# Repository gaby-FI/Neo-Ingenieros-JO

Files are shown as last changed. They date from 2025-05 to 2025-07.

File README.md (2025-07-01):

<div align="center">
  
   # Autonomous Robot Project for WRO - Future Engineers Category
  
</div>

## 🤖 About the Competition

The World Robot Olympiad (WRO) is a prestigious international competition that challenges students from around the globe to solve problems through creative, functional, and technically sound robotic solutions. One of its most engaging categories is **Future Engineers**, which focuses on developing advanced technologies to tackle real-world challenges, encouraging innovation, critical thinking, and collaborative work.

This year's challenge in the Future Engineers category is particularly exciting: to design and build an **autonomous vehicle** capable of making intelligent decisions and adapting to a dynamic environment. The challenge offers a unique opportunity for young engineers to explore the fundamentals of modern robotics, including motor control, sensor processing, and autonomous navigation.

---

## 🚗 Project Description

This repository documents the hardware and software architecture developed to build an autonomous vehicle designed to compete in the Future Engineers category of the WRO. The system has been carefully designed to address two specific challenges defined by the competition:

1. **Open Challenge**: The vehicle must complete three laps on a closed track, where inner walls are randomly placed each run. The robot must avoid collisions through accurate obstacle detection.
   
2. **Obstacle Challenge**: Along the route, the robot will encounter colored pillars acting as traffic signals. **Red** pillars indicate the robot should drive on the right, while **green** pillars indicate it should drive on the left. The vehicle must navigate without knocking over these signals, and at the end of the route, it must detect a **parking zone** and autonomously perform parallel parking.

The design integrates multiple technologies: ultrasonic sensors, a gyroscope, a Pixy2 camera, DC motors, and an H-bridge, all controlled by an Arduino Uno microcontroller. The system includes a voltage regulator and capacitors to protect sensitive components and ensure safe, stable operation. This documentation serves as a technical guide for the development process and as a reference for future teams participating in similar robotics challenges

---

## 🎯 Project Objective

The goal of this project is to design, build, and program an autonomous robot using open-source hardware, environmental sensors, and adaptive motion algorithms. The robot dynamically perceives its surroundings and makes decisions based on sensor feedback, enabling efficient navigation and autonomous obstacle avoidance.

**Core development goals:**

- Strengthen real-world engineering skills such as problem-solving and teamwork.
- Apply sensor-based motion control for precise navigation.
- Develop an optimized autonomous driving strategy for robotics challenges.
- Contribute to the open-source robotics community by documenting the solution for future teams.

---

## 🧩 Components Used

| Quantity | Component | Image | Description |
|:---:|:---:|:---:|:---:|
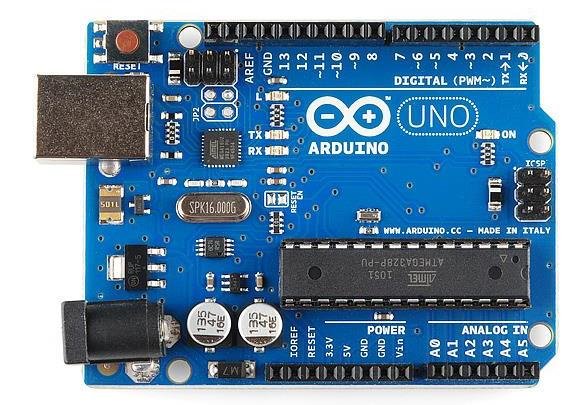
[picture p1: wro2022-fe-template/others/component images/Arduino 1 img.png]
| 1 | Arduino UNO |  | - ATmega328P microcontroller<br>- Operating voltage: 5V<br>- 14 digital pins (6 PWM)<br>- 6 analog inputs<br>- Memory: 32 KB flash, 2 KB SRAM, 1 KB EEPROM<br>- Communication: USB, UART, I2C, SPI<br>- Main system control, sensor reading, PWM signal generation, external communication<br>- Power supply: 7-12V<br>- Easy programming via Arduino IDE |
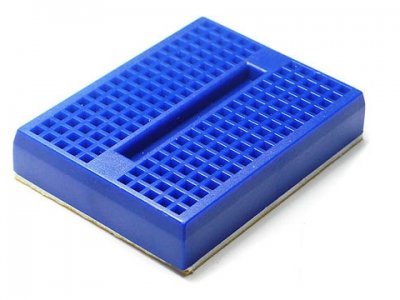
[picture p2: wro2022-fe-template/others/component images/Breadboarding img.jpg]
| 1 | Protoboard |  | - 830 solderless connection points<br>- Enables rapid prototyping<br>- Temporary connections between components<br>- Side rails for power (Vcc and GND)<br>- Compatible with standard cables and pins<br>- Plastic body with internal metal contacts<br>- Ideal for testing circuits without soldering |
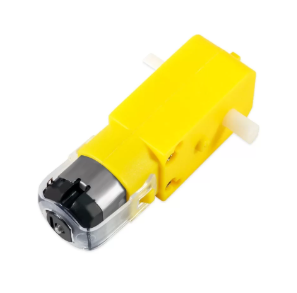
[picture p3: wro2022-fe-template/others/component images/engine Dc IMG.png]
| 2 | DC Engine |  | - Nominal voltage: 6–12V<br>- No-load current: ~300 mA<br>- Brushed DC motor<br>- Provides rotational motion<br>- Controlled via H-bridge for direction and speed<br>- Adequate torque for small vehicles<br>- Compact and lightweight |
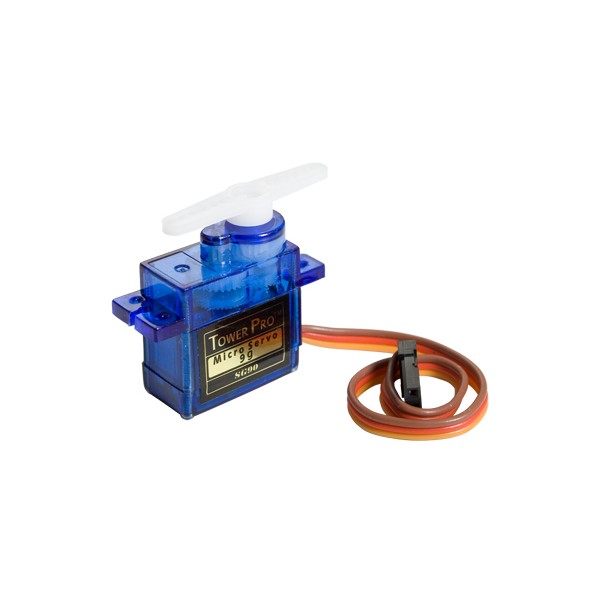
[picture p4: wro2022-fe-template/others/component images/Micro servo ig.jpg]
| 1 | Servo Motor |  | - Operating voltage: 4.8–6V<br>- Max current: ~500 mA<br>- Rotation angle: 0° to 180°<br>- Micro servo with plastic gears<br>- Precise angular position control via PWM<br>- Used for moving sensors or steering<br>- Compact and lightweight |
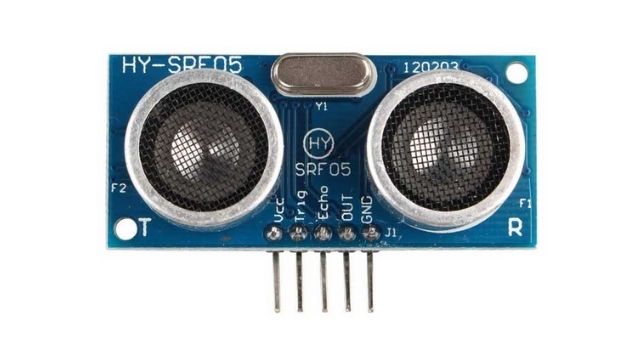
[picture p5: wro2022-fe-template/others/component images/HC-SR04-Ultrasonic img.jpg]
| 2 | Ultrasonic Sensors |  | - Operating voltage: 5V DC<br>- Range: 2 cm to 400 cm<br>- Accuracy: ±3 mm<br>- Ultrasonic frequency: 40 kHz<br>- Pins: Trigger and Echo<br>- Measures distance for obstacle avoidance<br>- Fast response time<br>- Detects objects in a straight line |
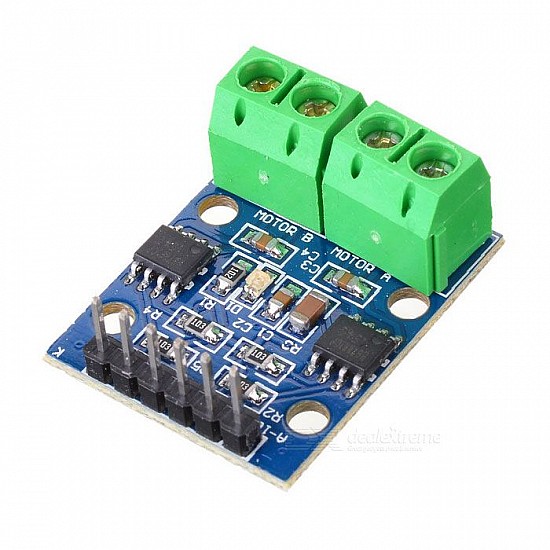
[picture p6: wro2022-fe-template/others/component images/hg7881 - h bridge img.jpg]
| 1 | HG7881 H-Bridge |  | - Operating voltage: 2.5–12V<br>- Max current: 800 mA per channel<br>- Dual channel motor driver<br>- Controls motor direction and speed via PWM<br>- Includes internal protection diodes<br>- Compact and efficient for small projects |
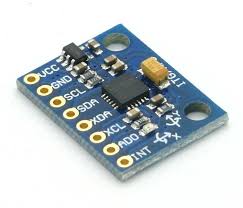
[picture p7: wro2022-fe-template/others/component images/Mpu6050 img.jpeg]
| 1 | MPU-6050 Gyroscope |  | - Power supply: 3.3V–5V<br>- 3-axis gyroscope and 3-axis accelerometer<br>- I2C communication<br>- High precision for orientation and balance<br>- Used for stabilization and motion tracking<br>- Low power consumption |
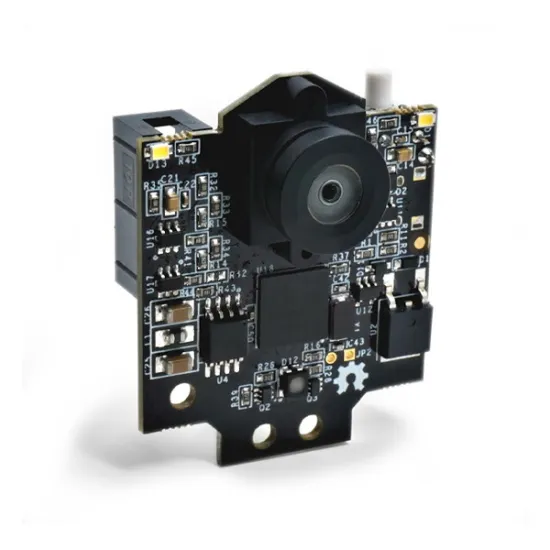
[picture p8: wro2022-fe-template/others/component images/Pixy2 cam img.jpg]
| 1 | Pixy2 Camera |  | - Operating voltage: 5–10V DC<br>- Communication: SPI, UART, I2C<br>- Smart sensor for object detection and tracking by color<br>- Internal image processing<br>- Sends processed data for decision making<br>- Used for advanced navigation and tracking |
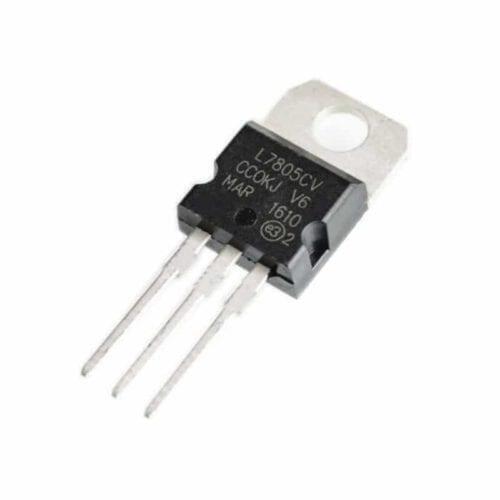
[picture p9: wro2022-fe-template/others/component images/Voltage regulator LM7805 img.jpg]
| 1 | Voltage Regulator |  | - Input voltage: 7–12V DC<br>- Fixed output: 5V DC<br>- Max current: typically 1A<br>- Provides stable and filtered voltage<br>- Overvoltage and thermal protection<br>- Protects sensitive components |
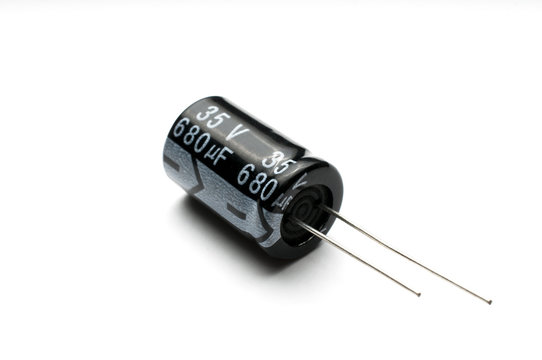
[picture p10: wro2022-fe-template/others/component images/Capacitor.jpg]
| 3 | Capacitors |  | - Electrolytic polarized capacitors (100μF, 10μF)<br>- Filters electrical noise and voltage spikes<br>- Stabilizes power supply<br>- Temporary charge storage<br>- Placed near regulators and modules<br>- Improves system stability and performance |

---

## 🔄 Relationship Between Electromechanical Components

- 🧠 The **Arduino UNO** acts as the brain of the vehicle, receiving data from sensors and sending control signals to actuators to coordinate movement.

- 📏 The **ultrasonic sensors** send distance information to the Arduino about side obstacles, allowing adjustment of direction and speed to avoid collisions.

- 🌀 The **MPU-6050 gyroscope** provides orientation and angular velocity data to the Arduino, which uses it to stabilize and correct the vehicle’s trajectory.

- 🎥 The **Pixy2 camera** complements the system’s vision by detecting objects and helping the Arduino follow routes or identify specific targets.

- ⚙️ The **HG7881 H-Bridge** receives commands from the Arduino to control the direction and speed of the **DC motors**, enabling forward, backward, and turning movements.

- 🔩 The **DC motors** execute the commands received from the HG7881, converting electrical energy into physical movement to drive the vehicle.

- 🔌 The **voltage regulator** supplies stable and safe voltage to the Arduino, sensors, servo, and HG7881 controller, protecting the electronic components.

- ↪️ The **servo motor** adjusts steering or sensor orientation based on control signals from the Arduino, improving maneuverability and environmental scanning.

- 🔋 The **capacitors** filter electrical noise and stabilize voltage, ensuring sensors, Arduino, and HG7881 operate without interference.

- 🧩 The **protoboard** facilitates physical connections and distribution of power and signals among all components, allowing organized and flexible assembly without soldering.

Each component depends on the information or energy it receives and transmits to others, creating a coordinated system where sensors detect the environment, the Arduino processes information, and actuators like motors and servos execute the necessary actions for the vehicle’s proper operation.

---
## 🚗 Strategy and Code Deployment for Autonomous Vehicle Project

The designed strategy combines mechanical, electronic, and perception components to simulate an intelligent vehicle that autonomously navigates a route under conditions similar to a controlled urban environment. The key elements to meet the challenges are:

- ⚙️ **Motorization and Steering:**  
  An electric motor drives the rear wheels of the vehicle, while a servo motor on the front axle allows left and right steering maneuvers, imitating a real car's steering system.

- 🎥 **Vision and Perception:**  
  A front-mounted camera enables detection of obstacle distances and traffic light colors (red or green), a critical decision factor to deviate either right or left. This visual component acts as the main perception system for the frontal environment.

- 📡 **Side Sensors:**  
  Two ultrasonic sensors located on the vehicle's sides measure the distance to obstacles on each side. Based on this data, the system determines the safest side to turn when detecting an obstruction or needing to take a curve.

- 🧭 **Orientation System:**  
  A gyroscope allows the vehicle to recognize its spatial orientation, record the initial position, and ensure that at the end of the route it parks parallel at the same starting position. This component is essential to meet the precise navigation requirements of the competition.

---
## 🧠 General Code Structure

This project is divided into functional modules that manage the behavior of an autonomous robot. Below is an overview of the main components of the code:

### 1. 📚 Library Imports
Essential libraries are included to:
- Control the **servo motor**.
- Enable **I2C communication**.
- Interface with the **MPU6050 gyroscope sensor**.

These libraries simplify hardware interaction and keep the code modular.

### 2. 🧩 Pin and Object Definitions
Microcontroller pins are assigned to the motors, ultrasonic sensors, and servo. Objects are also created for the servo and gyroscope to manage their operation.

### 3. ⚙️ Variables and Constants
Constants define decision thresholds (e.g., safe distances to avoid obstacles), and global variables are used to store values like rotation and timing.

### 4. 🔧 Initial Setup
In the `setup()` function:
- Pins are configured.
- I2C communication is initialized.
- The MPU6050 sensor is initialized and tested.
- The servo motor is attached.

The serial monitor confirms whether sensors are functioning correctly.

### 5. 📏 Ultrasonic Sensor Readings
Functions are included to measure distance using ultrasonic sensors on the left and right. This helps the robot detect obstacles and make directional decisions accordingly.

### 6. 🚗 Movement Functions
Basic movement functions are defined:
- **Move forward**
- **Move backward**
- **Stop**

These directly control the motor pins and determine the robot's mobility.

### 7. 🔁 Main Loop (`loop`)
The core of the program:
- Gyroscope data is captured.
- Rotational velocities are integrated to calculate orientation angles.
- Data is printed to the serial monitor for debugging or tuning.

There is also commented-out logic that could enable obstacle-avoidance behavior using the ultrasonic sensors.This modular structure makes it easy to scale the system, such as adding more sensors, a camera, or other peripherals without overcomplicating the main codebase.

---

## 💻 Code Compilation and Upload Process

### ⚙️ Development Environment Installation

To work on this project, you need the appropriate environment. It is recommended to use the Arduino IDE, preferably version 1.8.19 or higher, to ensure compatibility with all the libraries used and to avoid compilation errors.

**📚 Required Libraries:**

- `Servo.h`: Enables control of servo motors.  
- `Pixy2.h`: Provides functions necessary to communicate with the Pixy2 vision sensor.

These libraries can be easily installed from the Arduino IDE Library Manager or manually downloaded from their respective repositories.

### 🗂 Project Structure

The source code must be organized properly to ensure correct functionality. All `.ino` files should be located within the same folder, which must be named exactly as the main file (usually `main.ino`). This structure is required by the Arduino IDE to properly compile the different modules of the project.

### ⚙️ Compilation Process

Before compiling the code, configure the environment as follows:

1. Go to **Tools > Board**, and select the appropriate board model — in this case, **Arduino UNO**.  
2. In the same menu, select the COM port to which your device is connected.  
3. Once configured, click the **Verify** button (✔️) to compile the code. This action translates the source code to machine language and detects syntax errors or library issues.

### 🚀 Uploading the Program

Once the code is compiled:

1. Connect the Arduino UNO board to your computer via USB cable.  
2. Press the **Upload** button (➡️) in the IDE to load the program into the microcontroller’s memory.  
3. After upload completes, you can monitor the system behavior using the **Serial Monitor** accessible from **Tools > Serial Monitor**, which is especially useful for debugging and data flow verification

---

## 👥 Authors

This project was developed by the **Neo Engineers** team for the **WRO 2025** competition.  
Participants:  
- Nelson Figueroa  
- Gabriela Cisnero  
- Jesus Alfonzo

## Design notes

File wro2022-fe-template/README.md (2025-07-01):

Engineering materials
====

This repository contains engineering materials of a self-driven vehicle's model participating in the WRO Future Engineers competition in the season 2022.

## Content

* `t-photos` contains 2 photos of the team (an official one and one funny photo with all team members)
* `v-photos` contains 6 photos of the vehicle (from every side, from top and bottom)
* `video` contains the video.md file with the link to a video where driving demonstration exists
* `schemes` contains one or several schematic diagrams in form of JPEG, PNG or PDF of the electromechanical components illustrating all the elements (electronic components and motors) used in the vehicle and how they connect to each other.
* `src` contains code of control software for all components which were programmed to participate in the competition
* `models` is for the files for models used by 3D printers, laser cutting machines and CNC machines to produce the vehicle elements. If there is nothing to add to this location, the directory can be removed.
* `other` is for other files which can be used to understand how to prepare the vehicle for the competition. It may include documentation how to connect to a SBC/SBM and upload files there, datasets, hardware specifications, communication protocols descriptions etc. If there is nothing to add to this location, the directory can be removed.

---

<div align="center">
  
   # Autonomous Robot Project for WRO - Future Engineers Category
  
</div>

## 🤖 About the Competition

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

---

## 🚗 Project Description

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

---

## 🎯 Project Objective

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

**Core development goals:**

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

---

## 🧩 Components Used

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

---

## 🔄 Relationship Between Electromechanical Components

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

- 🔋 The **capacitors** filter electrical noise and stabilize voltage, ensuring sensors, Arduino, and HG7881 operate without interference.

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

---
## 🚗 Strategy and Code Deployment for Autonomous Vehicle Project

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

---
## 🧠 General Code Structure

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

These libraries simplify hardware interaction and keep the code modular.

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

The serial monitor confirms whether sensors are functioning correctly.

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

### 6. 🚗 Movement Functions
Basic movement functions are defined:
- **Move forward**
- **Move backward**
- **Stop**

These directly control the motor pins and determine the robot's mobility.

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

---

## 💻 Code Compilation and Upload Process

### ⚙️ Development Environment Installation

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

**📚 Required Libraries:**

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

### 🗂 Project Structure

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

### ⚙️ Compilation Process

Before compiling the code, configure the environment as follows:

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

### 🚀 Uploading the Program

Once the code is compiled:

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

---

## 👥 Authors

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

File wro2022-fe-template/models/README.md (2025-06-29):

Models irectory
===

This directory is for the files for **models used by 3D printers, laser cutting machines, and CNC machines** to produce the vehicle elements.

It includes all the digital design files required to fabricate structural and mechanical parts of the vehicle, such as:

- Chassis components
- Sensor or camera mounts
- Motor brackets
- Enclosures or protective covers

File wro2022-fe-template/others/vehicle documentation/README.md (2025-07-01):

<div align="center">
  
# Vehicle Documentation

### Development and construction of an autonomous vehicle for the World Robot Olympiad (WRO)
---
</div>

This document provides a detailed description of the development, construction, and validation of an autonomous vehicle designed to compete in the World Robot Olympiad (WRO). The main technical objective was to enable the robot to complete three laps on a closed circuit, accurately avoiding walls and intermediate obstacles.

Throughout the process, challenges were addressed in three key areas: mechanics, electronics, and intelligent control. Through multiple technical iterations, both the physical design and navigation algorithm were optimized, resulting in a robust, reliable system capable of meeting the competition's demanding requirements

---

## ✏️ Phase 1 – Concept Design and LEGO-Based Prototype

The initial phase focused on designing the robot based on dimensional sketches and functional concepts to ensure maneuverability and performance.

### 🧱 Physical Build

- A preliminary chassis was constructed using **LEGO pieces**, which allowed quick prototyping and a clear visual of the intended structure.
- Special attention was given to selecting **agile wheels**, aiming for smooth mobility and accurate turns.

### 🔌 Initial Electronics Setup

- **Microcontroller:** Arduino UNO
- **Ultrasonic Sensors (2x):** Used for obstacle detection in front and side directions  
- **Rear-Wheel Movement:** Driven by a DC motor  
- **Motor Controller:** L298N H-Bridge  
- **Power Supply:** Elegoo battery  
- **Arduino Adapter Board:** Used to simplify wiring and component connections  

This stage provided the robot with basic movement capabilities and established a foundation for future integration.

---

## ⚙️ Phase 2 – Sensor Integration and Functional Expansion

Once the robot could move independently, additional components were added to meet competition demands and allow environmental interaction.

### 🔍 Installed Modules

- **Pixy2 Camera:** Enabled object or color tracking through visual input  
- **Servo Motor:** Allowed the robot to control the steering angle and change direction autonomously  

These upgrades allowed the robot to interpret its surroundings and make decisions based on sensor input, increasing its level of autonomy.

<div align="center">
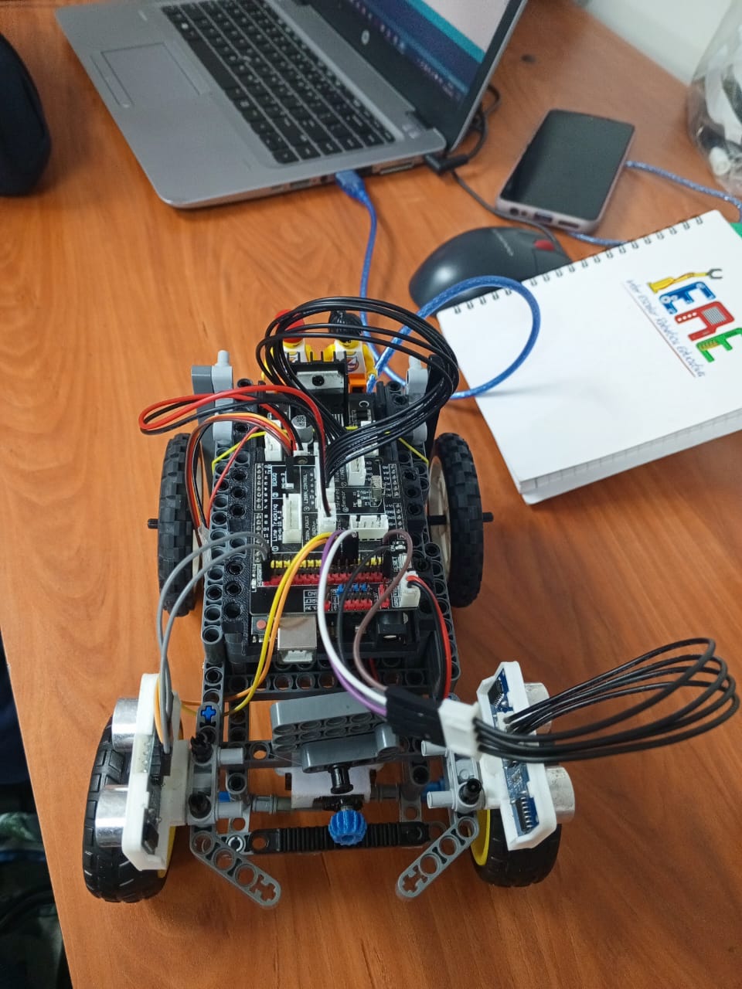
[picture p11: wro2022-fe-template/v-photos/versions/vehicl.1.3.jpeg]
  
  
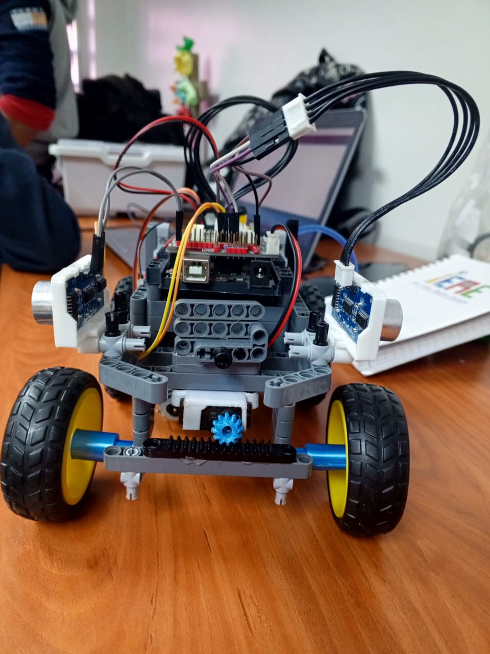
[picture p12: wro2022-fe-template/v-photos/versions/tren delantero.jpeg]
  

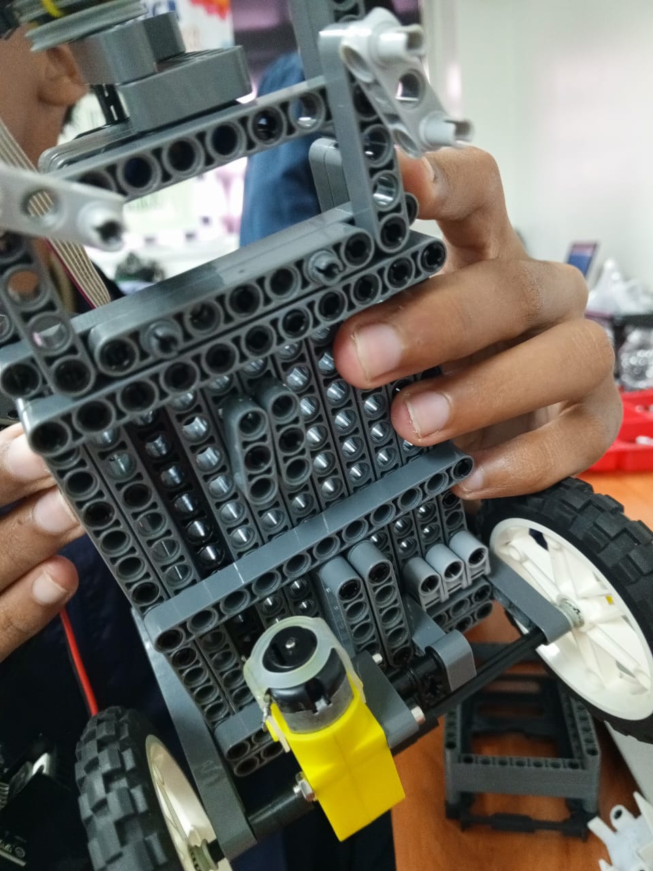
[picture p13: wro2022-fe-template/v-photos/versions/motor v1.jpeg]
  
</div>

---

## 🛠️ Phase 3 – Hardware Reinforcement and Electrical Optimization

After testing, several issues were identified with the robot's structure and electrical system, leading to necessary improvements.

### 🧩 Mechanical Adjustments

- The **rear wheel system** built with LEGO was unstable. It was replaced with a **3D-printed gear mechanism**, enabling better torque transfer, improved rotation smoothness, and higher vehicle speed.

### ⚡ Power and Control Upgrades

- The **Elegoo battery** was replaced by **three 3.5V batteries connected in series**, offering increased voltage and more consistent power output.
- The **L298N motor driver** was swapped for an **HG7881 driver**, which consumed less voltage and required fewer GPIO pins on the microcontroller.

These changes greatly enhanced the robot’s mechanical stability, energy efficiency, and response time.

---

## 🚀 Phase 4 – Final Additions and Advanced Control

In the final development phase, the robot was equipped with advanced modules to increase precision and control capabilities.

### 🧠 New Features

- **Gyroscope:** Used to store the robot’s initial coordinates and return to the original position (self-parking logic)
- **Power Button:** Manually activates battery flow to the circuit
- **Breadboard:** Used to expand ground and voltage lines, improving wiring organization
- **Upgraded Front Steering:** Implemented using **3D-printed components**, increasing directional control and structural strength

<div align="center">
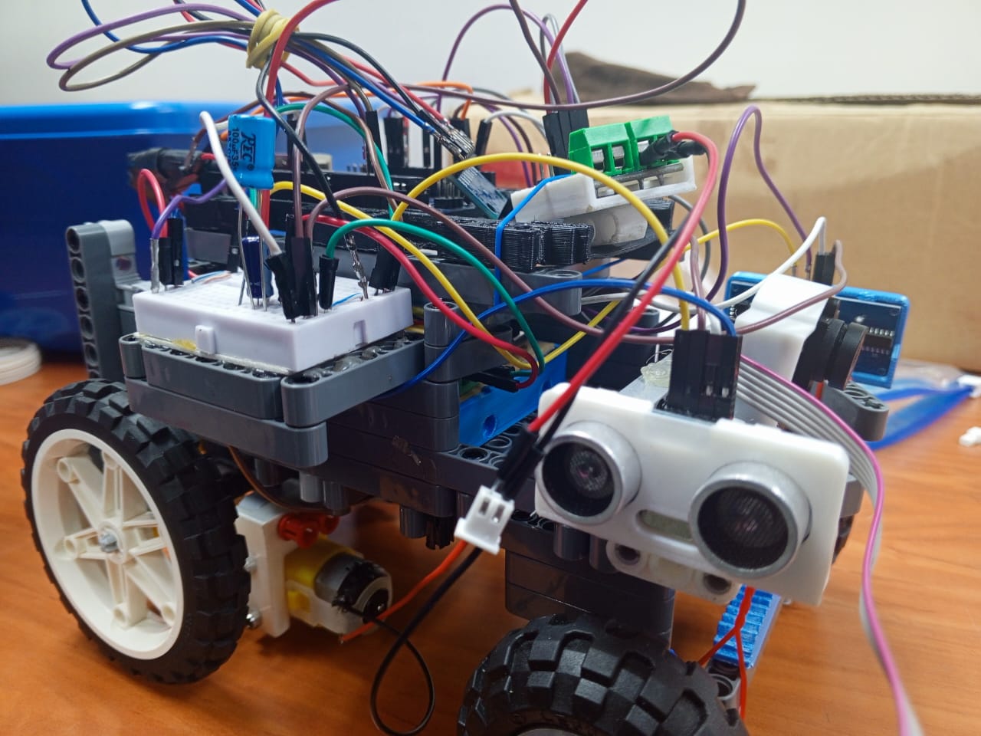
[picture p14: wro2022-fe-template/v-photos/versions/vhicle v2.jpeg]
  
  
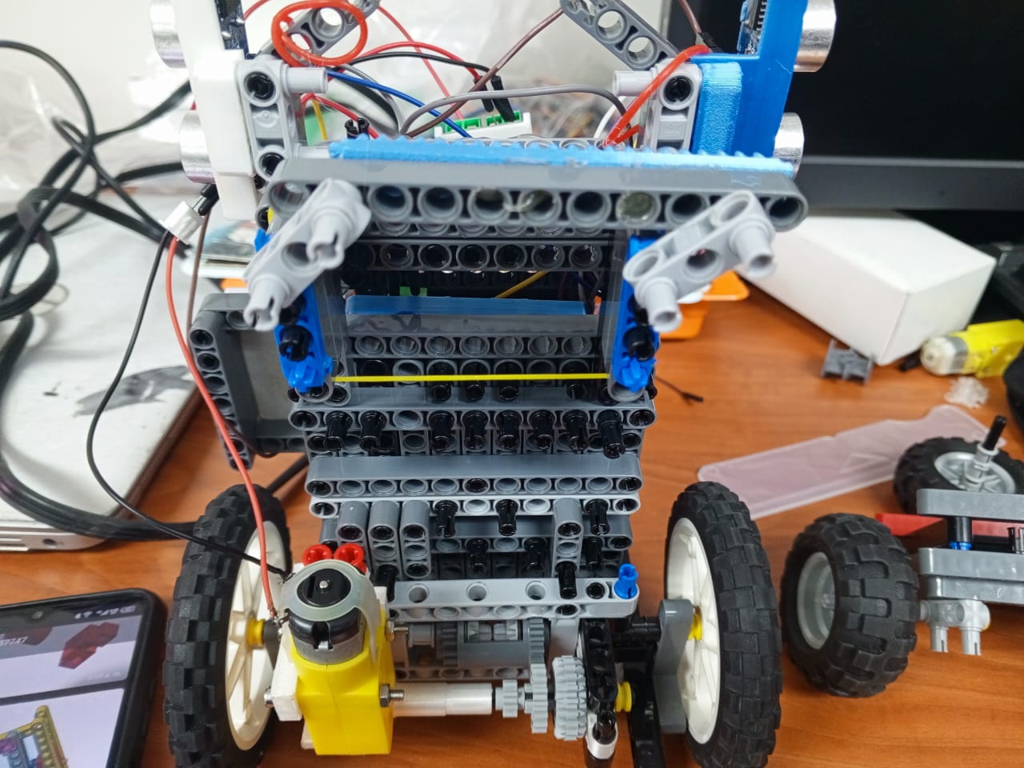
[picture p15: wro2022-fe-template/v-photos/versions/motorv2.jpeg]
  

</div>

## 🧠 Conclusion

The robot's development followed a structured, iterative approach. From simple sketches and LEGO prototyping to advanced sensor integration and 3D-printed enhancements, the vehicle evolved into a robust, efficient, and autonomous machine ready for competition. The final design prioritizes stability, power efficiency, and intelligent navigation.

---

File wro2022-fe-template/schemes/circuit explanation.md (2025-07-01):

# 🤖 Circuit Diagram - WRO Future Engineers

This repository contains the wiring diagram for the electromechanical system of the autonomous vehicle developed for the **WRO Future Engineers 2022** project. The system integrates motors, sensors, controllers, and a regulated power supply to allow coordinated and safe operation of the vehicle.

## 🧩 Components Used

| Quantity | Component | Image | Description |
|:---:|:---:|:---:|:---:|
| 1 | Arduino UNO |  | Main microcontroller board used to control all components. |
| 1 | Protoboard |  | Solderless board used for building and testing electronic circuits. |
| 1 | DC engine |  | Motors used for the vehicle’s locomotion. |
| 1 | Servo Motor |  | Controls the steering or sensor orientation. |
| 2 | Ultrasonic Sensors |  | Distance measurement (Left and Right side). |
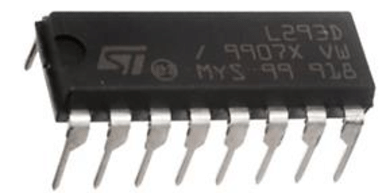
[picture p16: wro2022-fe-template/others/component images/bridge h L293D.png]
| 1 | L293D H bridge |  | Motor driver that allows control of direction and speed for two DC motors.(Used only in the diagram; the actual vehicle circuit uses an HG7881 instead.) |
| 1 | MPU-6050 Gyroscope |  | Detects angular motion and helps with orientation. |
| 1 | Pixy2 Camera |  | Visual object detection system. |
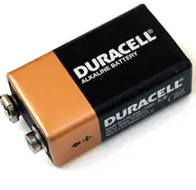
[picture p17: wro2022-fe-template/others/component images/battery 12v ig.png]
| 1 | 12V Battery |  | 12V power source for motors and logic components. (In the actual circuit, three 3.5V batteries connected in series using a battery holder are used instead). |
| 1 | Voltage Regulator |  | Steps down 12V to 5V to protect components from overvoltage. |
| 2 | Condenser |  | Filters electrical interference and stabilizes voltage in the circuit. |

## 📷 Circuit Diagram

> Full connection diagram (created in Tinkercad)

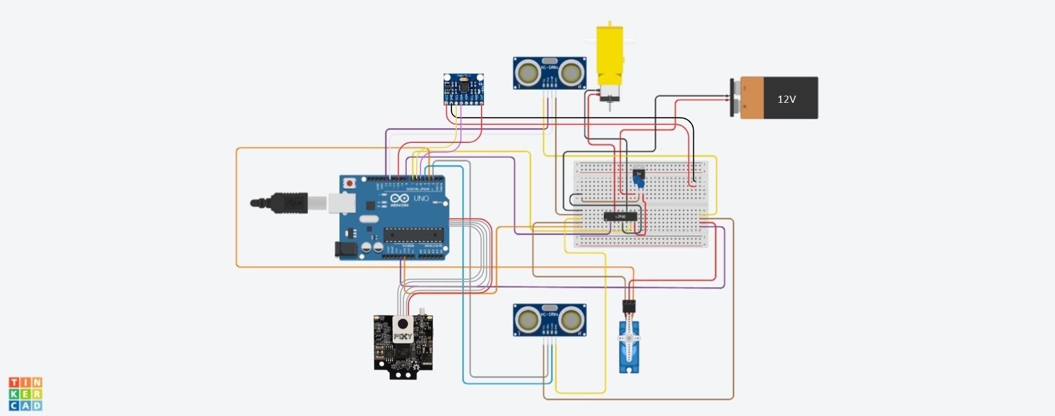
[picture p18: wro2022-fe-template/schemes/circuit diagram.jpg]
Circuit diagram


## 🔌 Wiring Explanation

### 🔊 Ultrasonic Sensors

**Left sensor:**
- Trigger (purple) → Pin 13  
- Echo (white) → Pin 12  
- VCC (yellow) → Breadboard power rail  
- GND (brown) → Breadboard ground rail  

**Right sensor:**
- Trigger (gray) → Pin 2  
- Echo (blue) → Pin 4  
- VCC → Breadboard power rail  
- GND → Breadboard ground rail  

### ⚙️ DC Motors and H-Bridge (L298N)

- Motors connected to channel A of the H-Bridge (purple and gray wires)  
- IN1 → Pin 8  
- IN2 → Pin 7  
- H-Bridge GND → Breadboard ground  
- H-Bridge VCC → Output from voltage regulator  

### 🌀 Gyroscope MPU-6050

- VCC (red) → Breadboard power rail  
- GND (black) → Breadboard ground rail  
- SDA (purple) → Pin A4  
- SCL (gold) → Pin A5  
- INT (thin red) → Pin 11  

### 🔁 Servo Motor

- Signal (orange) → Pin 3  
- VCC (red) → Power rail  
- GND (brown) → Ground rail  

### 📷 Pixy2 Camera

- Connected to Arduino via dedicated interface cable (UART or SPI).

### 🔋 Voltage Regulator Circuit

- **12V Battery:**
  - Positive → Right leg of the regulator (input)  
  - Negative → Shared ground  
- **Regulator:**
  - Left leg → 5V output (goes to H-Bridge and breadboard)  
  - Middle leg → GND (connected to ground rail)  
- **Capacitors:**
  - One large capacitor between output and GND  
  - One smaller capacitor between input and GND  

> This setup reduces the 12V from the battery to 5V to avoid overloading the H-Bridge and ensures safe current regulation to protect the motors and board.

## ⚠️ Recommendations

- Make sure all grounds (GND) are unified to avoid floating references.  
- Motors are powered directly from the H-Bridge and battery.  
- The voltage regulator prevents current spikes that could damage components and guarantees stable 5V output for the electronics.

## ✅ Justification of Component Selection
### 🧠 **Arduino UNO**  
Chosen as the main microcontroller for its ease of programming, multiple I/O ports, and compatibility with various modules. It handled all sensor inputs, motor control, and decision-making processes efficiently during the development and testing stages.

### ⚙️ **DC Motor**  
Used for the main propulsion system of the vehicle. These motors convert electrical energy into mechanical movement, enabling the robot to navigate the track reliably with sufficient torque and speed.

### 🔌 **Breadboard**  
Used to simplify prototyping without soldering. It allowed rapid assembly and reconfiguration of the circuit, especially for distributing power and connecting sensors during testing and debugging phases.

### 📏 **HC-SR04 Ultrasonic Sensor**  
Implemented for obstacle detection and distance measurement. Mounted on the sides, these sensors allowed the vehicle to maintain a safe distance from walls and objects, supporting lateral alignment and collision avoidance.

### 🌀 **MPU-6050**  
Provided orientation and motion data through its built-in accelerometer and gyroscope. This information was used to stabilize the vehicle and assist in trajectory adjustments during operation.

### ↪️ **Micro Servo Motor (SG90)**  
Controlled the front steering mechanism of the vehicle. Based on inputs from the ultrasonic sensors and vision system, the servo motor dynamically adjusted the wheel direction to avoid obstacles and follow the correct path.

### 🎥 **Pixy2 Cam**  
Served as the visual processing unit for the vehicle. It enabled real-time object detection and line tracking, allowing the robot to follow a predefined path or identify specific targets during competition scenarios.

### 🔋 **Capacitors**  
Added to the circuit to filter out electrical noise and stabilize voltage across sensitive components. This ensured smoother operation, especially under varying motor loads.

### 🔋 **12V Battery**  
Served as the primary power source for motors and control modules. While a 12V battery is shown in the diagram for simplicity, the actual vehicle used three 3.7V batteries connected in series via a battery holder (totaling ~11.1V), which met all power requirements effectively.

### ⚡ **Voltage Regulators**  
Used to supply consistent 5V output to logic-level components from a higher voltage input. This protected the microcontroller and sensors from voltage spikes or drops.

### 🔀 **HG7881 H-Bridge Motor Driver** *(used in the final vehicle)*  
Enabled bidirectional control of DC motors with PWM support. Its compact design and efficient performance made it ideal for integrating into the mobile platform, controlling both speed and direction.

### 🔄 **L293D H-Bridge** *(used only in the diagram)*  
Included in the schematic as a visual placeholder. It supports bidirectional control of two DC motors and represents the logic of the system. *(In the physical vehicle, the HG7881 was used instead.)*

### 🔋 **Batería de 12V**  
Utilizada como fuente principal de energía para los motores y módulos de control. Aunque en el diseño final se utilizaron tres baterías de 3.7V conectadas en serie mediante un portapilas (equivalente a ~11.1V), la batería de 12V fue representada en el esquema por simplicidad y disponibilidad. Ambas opciones cumplen con los requerimientos de potencia del sistema.

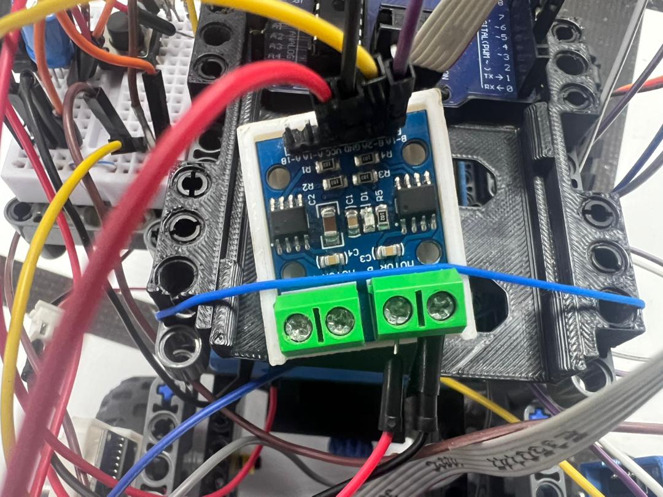
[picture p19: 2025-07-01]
wro2022-fe-template/v-photos/vehicle/puente h.jpeg

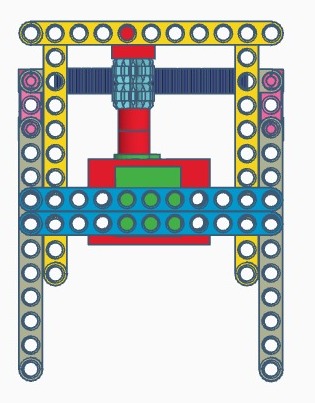
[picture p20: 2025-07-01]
wro2022-fe-template/models/front mechanism/part1.1.jpeg

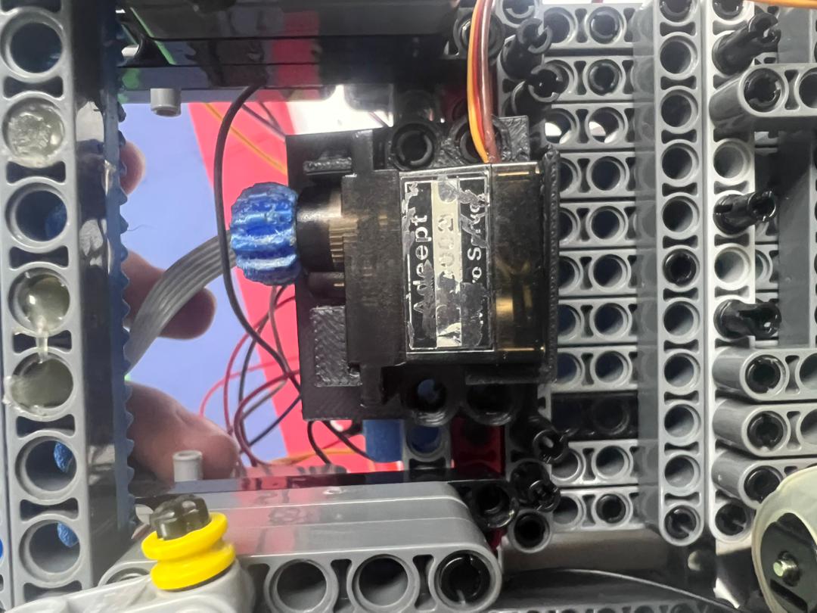
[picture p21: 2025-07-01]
wro2022-fe-template/v-photos/vehicle/servo.jpeg

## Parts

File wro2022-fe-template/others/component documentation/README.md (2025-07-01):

Component documentation
===

This directory contains technical documentation (datasheets) of the electromechanical components used in the self-driven vehicle developed for the WRO Future Engineers 2022 competition.

Each file provides specifications, electrical characteristics, pin configurations, and usage guidelines of the components involved in the system's control and sensing mechanisms. These documents are essential for integration, troubleshooting, and future development.

Included components:

- **Arduino UNO**: Main microcontroller used for program execution and peripheral control.
- **DC Motor**: Converts electrical energy into mechanical rotation for propulsion and actuation.
- **Breadboarding**: Used for rapid prototyping and testing of circuit connections.
- **HC-SR04 Ultrasonic Sensor**: Used for distance measurement and obstacle detection.
- **MPU-6050**: Motion sensor that combines accelerometer and gyroscope.
- **Micro servo motor**: Used for mechanical movements such as steering.
- **Pixy2 Cam**: Vision sensor for color-based object tracking and line following.
- **Capacitors**: Provide voltage smoothing and noise filtering in power lines and signal circuits.
- **Voltage Regulators**: Ensure stable voltage output to critical components, protecting against fluctuations.
- **HG7881 H-Bridge Motor Driver**: Dual H-bridge module for controlling DC motors in both directions with speed modulation.
- **L293D** : Quadruple H-bridge motor driver IC that allows bidirectional control of up to two DC motors, ideal for basic robotic movement and direction control.

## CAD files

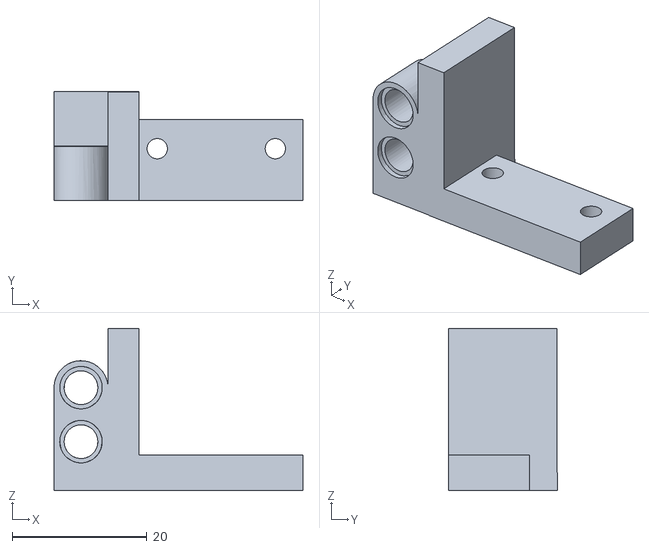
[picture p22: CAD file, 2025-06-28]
wro2022-fe-template/models/engine base/Base Motor DC p2.stl
36.9 x 16.2 x 24.0

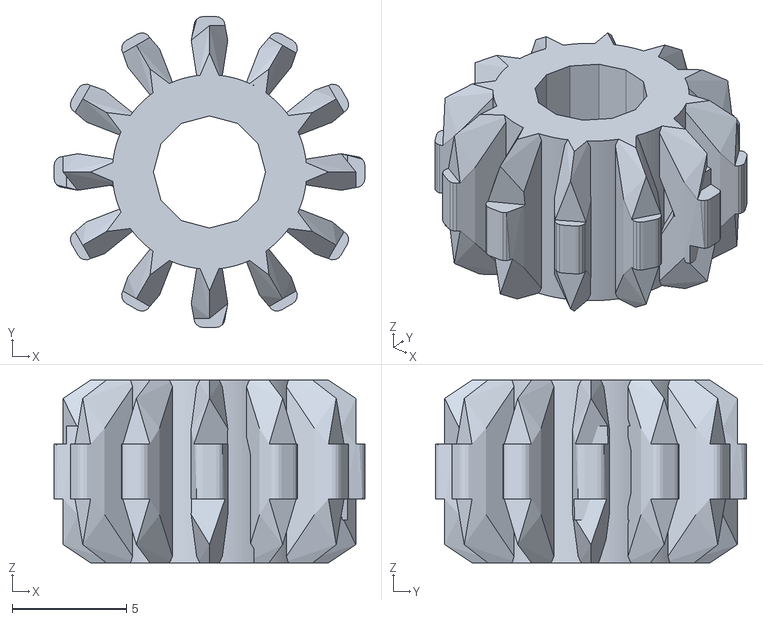
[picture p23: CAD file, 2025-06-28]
wro2022-fe-template/models/extra pieces/EngranajePequeLego.stl
13.6 x 13.6 x 8.00

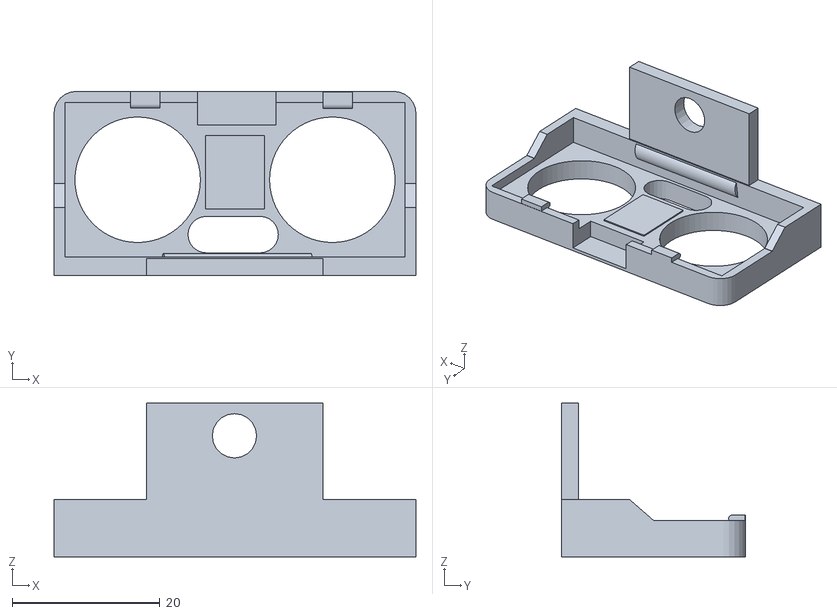
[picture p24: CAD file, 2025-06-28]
wro2022-fe-template/models/HC-SR04-Ultrasonic/US_Sensor1.stl
49.0 x 25.0 x 20.8

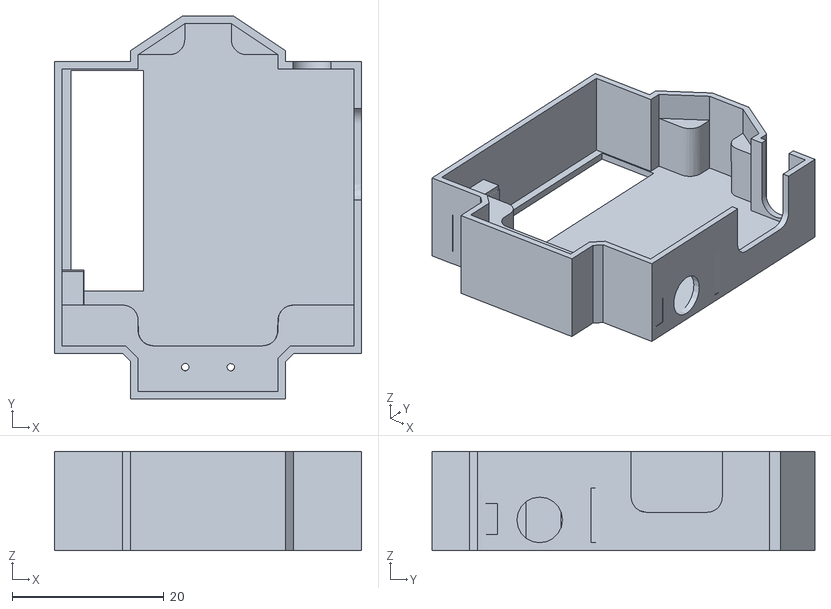
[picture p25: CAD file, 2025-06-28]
wro2022-fe-template/models/Pixy 2 cam/Pixy2 Cam Lego.stl
40.4 x 50.4 x 13.0

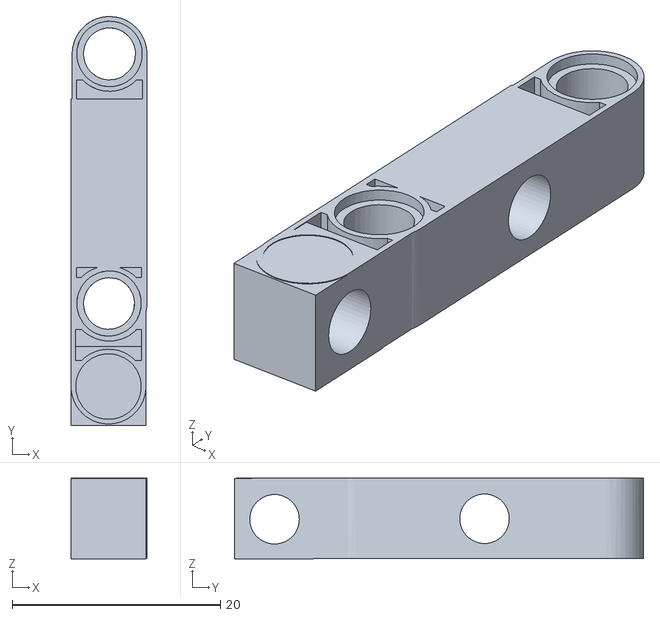
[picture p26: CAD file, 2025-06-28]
wro2022-fe-template/models/engine base/Base Motor DC p3.stl
7.30 x 39.3 x 7.75

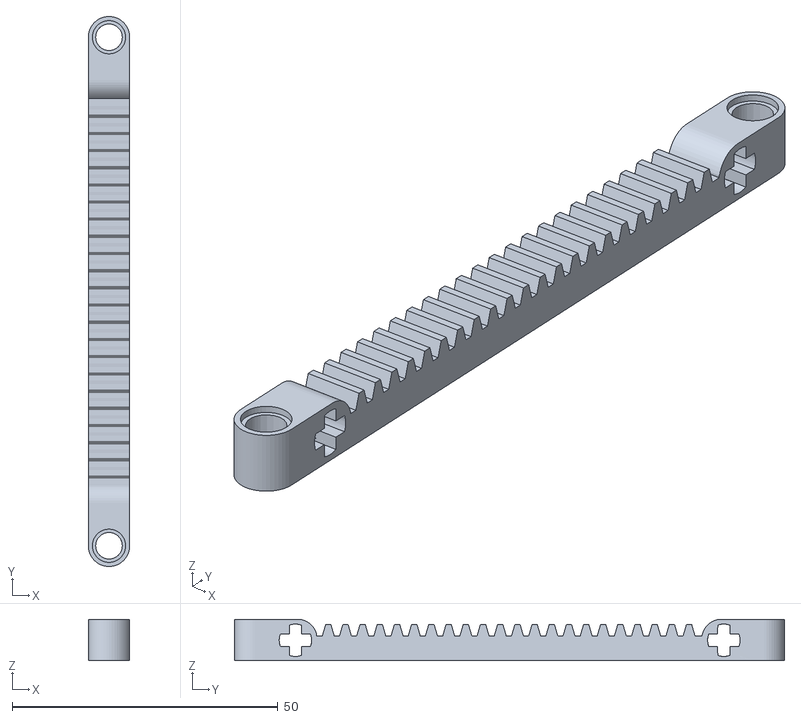
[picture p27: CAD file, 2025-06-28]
wro2022-fe-template/models/extra pieces/Eng_plano_103mm.stl
7.80 x 103.4 x 7.80

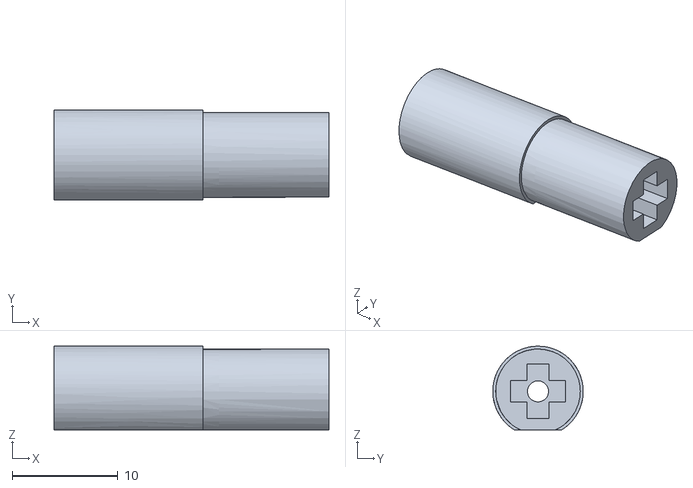
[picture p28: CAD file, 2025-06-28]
wro2022-fe-template/models/engine base/Base Motor DC p4.stl
26.0 x 8.56 x 7.92

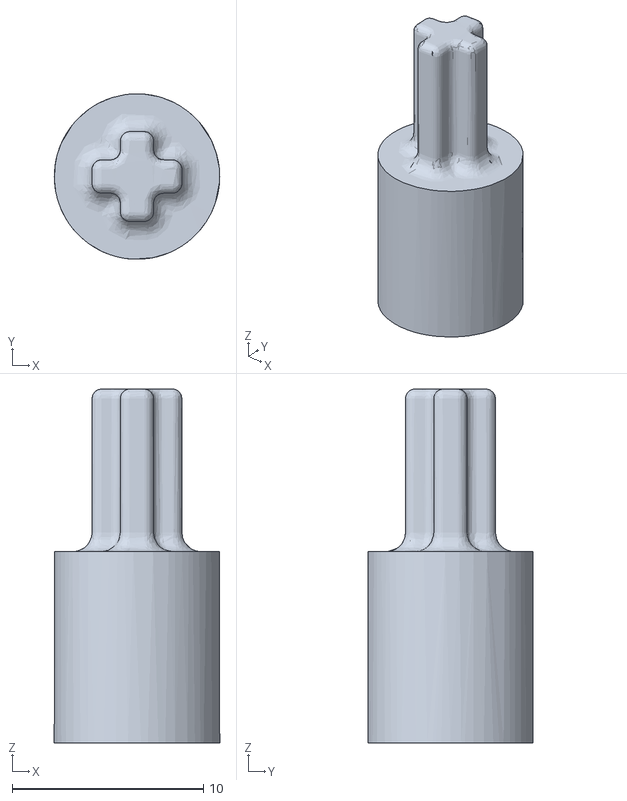
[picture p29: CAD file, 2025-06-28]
wro2022-fe-template/models/extra pieces/ConectorDCLego3.stl
8.65 x 8.65 x 18.5

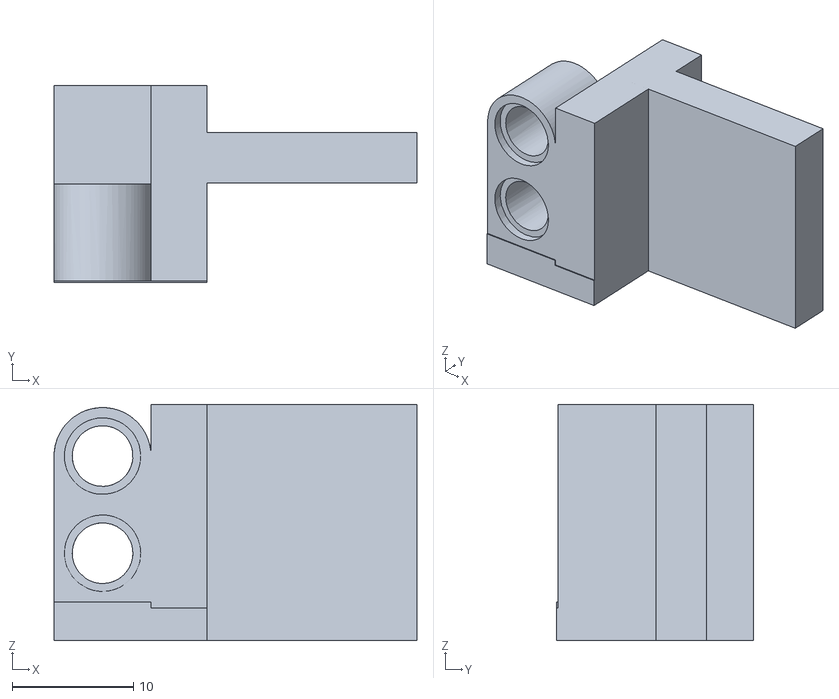
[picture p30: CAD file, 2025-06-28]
wro2022-fe-template/models/engine base/Base Motor DC p1.stl
29.9 x 16.2 x 19.5

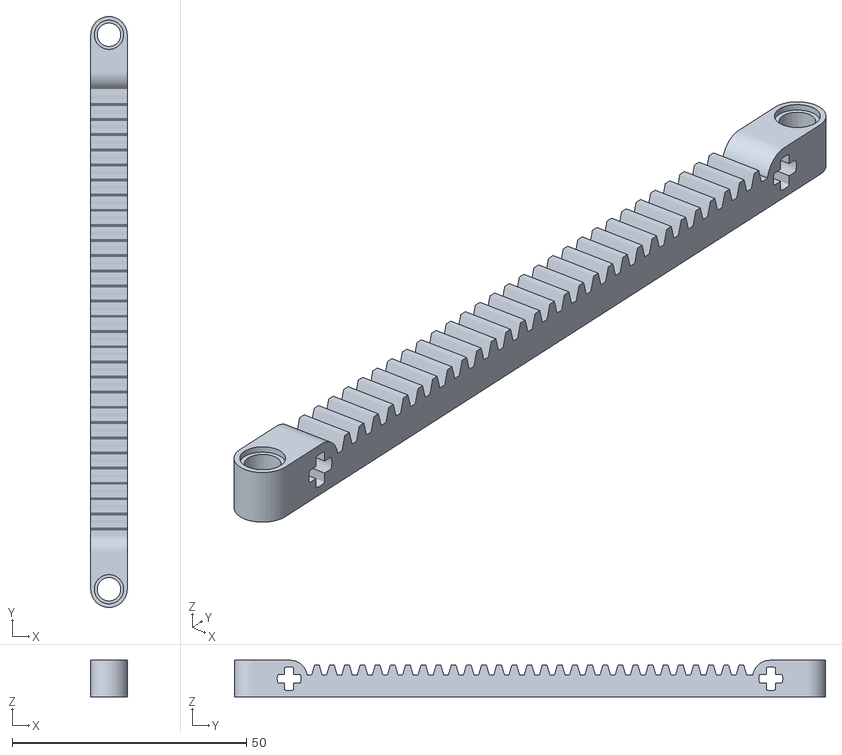
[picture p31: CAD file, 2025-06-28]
wro2022-fe-template/models/extra pieces/Eng_plano_126mm.stl
7.81 x 126.0 x 7.80

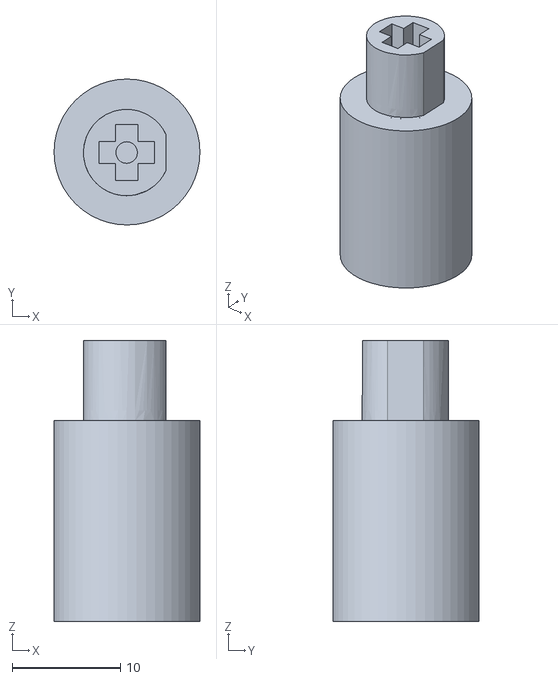
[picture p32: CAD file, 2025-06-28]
wro2022-fe-template/models/extra pieces/ConectorDCLego2.stl
13.5 x 13.5 x 26.0

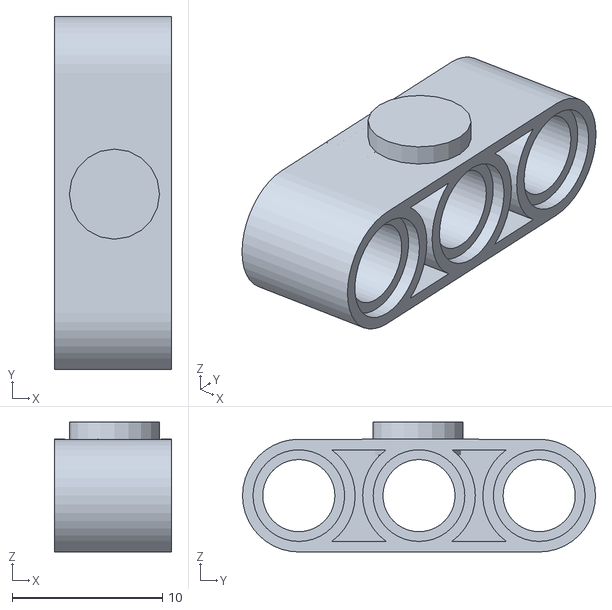
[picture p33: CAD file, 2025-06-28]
wro2022-fe-template/models/extra pieces/PiezaLego1.stl
7.80 x 23.5 x 8.65

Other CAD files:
wro2022-fe-template/models/extra pieces/ConectorDCLego1.stl

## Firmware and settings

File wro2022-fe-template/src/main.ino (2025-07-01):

// ======== LIBRARIES ========
#include <Servo.h>        // Library to control the servo motor
#include <Wire.h>         // Library for I2C communication (used with gyroscope)
#include <MPU6050.h>      // Library for the MPU6050 gyroscope
#include <I2Cdev.h>       // Library for I2C device communication

// ======== MOTOR PINS ========
#define MOTOR_DER_ADELANTE 8   // Right motor forward pin
#define MOTOR_DER_ATRAS 7      // Right motor backward pin

// ======== ULTRASONIC SENSOR PINS ========
#define trigpinI 13   // Trigger pin for left ultrasonic sensor
#define echopinI 12   // Echo pin for left ultrasonic sensor
#define trigpinD 2    // Trigger pin for right ultrasonic sensor
#define echopinD 4    // Echo pin for right ultrasonic sensor

// ======== OBJECTS ========
Servo servito;         // Servo motor object
MPU6050 sensor;        // Gyroscope object

// MPU6050 address can be 0x68 or 0x69 depending on the AD0 pin state.
// If not specified, it defaults to 0x68.

// ======== CONSTANTS ========
const int cfloja = 30;            // Acceptable margin between sensor readings
const int umbralGiro = 100;       // If distance is greater than this, it's considered "free space"
const int umbralCorreccion = 10;  // Allowed difference before correcting trajectory

int giros = 0;  // Counter for turns made

// ======== RAW GYROSCOPE VALUES ========
int gx, gy, gz;                   // Raw rotation values from gyroscope (X, Y, Z axes)
long tiempo_prev, dt;            // Time tracking for integration
float gc_ang_x, gc_ang_y;        // Calculated angular position (X and Y)
float gc_ang_x_prev, gc_ang_y_prev;  // Previous angles to integrate over time

void setup() {
  // === MOTOR SETUP ===
  pinMode(MOTOR_DER_ADELANTE, OUTPUT);
  pinMode(MOTOR_DER_ATRAS, OUTPUT);

  // === ULTRASONIC SENSOR SETUP ===
  pinMode(trigpinI, OUTPUT);
  pinMode(echopinI, INPUT);
  pinMode(trigpinD, OUTPUT);
  pinMode(echopinD, INPUT);

  // === SERVO SETUP ===
  servito.attach(3);   // Attach the servo to digital pin 3

  // === SERIAL AND SENSOR INITIALIZATION ===
  Serial.begin(9600);       // Begin serial communication
  Wire.begin();             // Initialize I2C communication
  sensor.initialize();      // Initialize MPU6050

  if (sensor.testConnection()) Serial.println("Sensor initialized correctly");
  else Serial.println("Sensor initialization failed");

  tiempo_prev = millis();   // Store the initial time

  // NOTE: The following lines reference an undefined 'mpu' object.
  // If you use `MPU6050 sensor;`, then `mpu.begin()` and `mpu.getAngleZ()` will cause errors.
  // Uncomment and adjust only if using a different MPU6050 library:
  /*
  mpu.begin();
  delay(1000);
  mpu.calcOffsets();  // Calibrate at rest
  mpu.update();
  anguloInicial = mpu.getAngleZ(); // Store initial orientation
  */
}

// ======== ULTRASONIC MEASUREMENT FUNCTIONS ========

// Measure distance using the left ultrasonic sensor
long MDizquierda(int trigI, int echoI) {
  digitalWrite(trigI, LOW);
  delayMicroseconds(2);
  digitalWrite(trigI, HIGH);        // Send ultrasonic pulse
  delayMicroseconds(10);
  digitalWrite(trigI, LOW);
  long duracion = pulseIn(echoI, HIGH);   // Measure echo return time
  return duracion * 0.0343 / 2;           // Convert time to distance in cm
}

// Measure distance using the right ultrasonic sensor
long MDderecha(int trigD, int echoD) {
  digitalWrite(trigD, LOW);
  delayMicroseconds(2);
  digitalWrite(trigD, HIGH);        // Send ultrasonic pulse
  delayMicroseconds(10);
  digitalWrite(trigD, LOW);
  long duracion = pulseIn(echoD, HIGH);   // Measure echo return time
  return duracion * 0.0343 / 2;           // Convert time to distance in cm
}

// ======== BASIC MOVEMENT FUNCTIONS ========

void avanzar() {
  digitalWrite(MOTOR_DER_ADELANTE, 1);   // Move right motor forward
  digitalWrite(MOTOR_DER_ATRAS, 0);
}

void retroceder() {
  digitalWrite(MOTOR_DER_ADELANTE, 0);
  digitalWrite(MOTOR_DER_ATRAS, 1);     // Move right motor backward
}

void detener() {
  digitalWrite(MOTOR_DER_ADELANTE, 0);
  digitalWrite(MOTOR_DER_ATRAS, 0);     // Stop right motor
}

// ======== MAIN LOOP ========
void loop() {
  // Read gyroscope rotational velocities
  sensor.getRotation(&gx, &gy, &gz);

  // Calculate rotation angles by integrating velocity over time
  dt = millis() - tiempo_prev;
  tiempo_prev = millis();

  girosc_ang_x = (gx / 131.0) * dt / 1000.0 + girosc_ang_x_prev;
  girosc_ang_y = (gy / 131.0) * dt / 1000.0 + girosc_ang_y_prev;

  girosc_ang_x_prev = girosc_ang_x;
  girosc_ang_y_prev = girosc_ang_y;

  // Display calculated angles (X and Y rotation)
  Serial.print("Rotation X: ");
  Serial.print(girosc_ang_x);
  Serial.print("\tRotation Y: ");
  Serial.println(girosc_ang_y);

  delay(100);

  /*
  // Example logic to compare distances
  Serial.print(MDizquierda(trigpinI, echopinI));
  Serial.print("\n");
  Serial.print(MDderecha(trigpinD, echopinD));

  if (MDizquierda > MDderecha) {
    servito.write(90);  // Turn servo to center
  } else if (MDderecha > MDizquierda) {
    servito.write(20);  // Turn servo slightly left
  }
  delay(1000);
  */
}

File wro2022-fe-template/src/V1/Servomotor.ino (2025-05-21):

// Servomotor
  #include <Servo.h>
  Servo servito;
// Velocidad
  #define Activa1 6
  #define Activa2 5
// Motor
  #define MOTOR_IZQ_ADELANTE 11
  #define MOTOR_IZQ_ATRAS 9
  #define MOTOR_DER_ADELANTE 8
  #define MOTOR_DER_ATRAS 7
// Ultrasonidos
  #define trigpin1 5
  #define echopin1 4
  #define trigpin2 3
  #define echopin2 2
// Velocidad
  int velocidad=200;




// Definir función motor
void avanzarAdelante() {
  digitalWrite(MOTOR_IZQ_ADELANTE, 0);
  digitalWrite(MOTOR_IZQ_ATRAS, 1);
  digitalWrite(MOTOR_DER_ADELANTE, 0);
  digitalWrite(MOTOR_DER_ATRAS, 1);
  delay(5000);
  digitalWrite(MOTOR_IZQ_ATRAS, 1);
  digitalWrite(MOTOR_DER_ATRAS, 1);
}
void retroceder() {
  digitalWrite(MOTOR_IZQ_ADELANTE, 1);
  digitalWrite(MOTOR_IZQ_ATRAS, 0);
  digitalWrite(MOTOR_DER_ADELANTE, 1);
  digitalWrite(MOTOR_DER_ATRAS, 0);
  delay(5000);
  digitalWrite(MOTOR_IZQ_ADELANTE, 0);
  digitalWrite(MOTOR_DER_ADELANTE, 0);
}

// Definir giros
void girarDerecha() {
  digitalWrite(MOTOR_IZQ_ADELANTE, 0);
  digitalWrite(MOTOR_IZQ_ATRAS, 0);
  digitalWrite(MOTOR_DER_ADELANTE, 1);
  digitalWrite(MOTOR_DER_ATRAS, 1);
  delay(500); // Ajusta el tiempo de giro según sea necesario
  detenerMotor();
}
void girarIzquierda() {
  digitalWrite(MOTOR_IZQ_ADELANTE, 0);
  digitalWrite(MOTOR_IZQ_ATRAS, 1);
  digitalWrite(MOTOR_DER_ADELANTE, 1);
  digitalWrite(MOTOR_DER_ATRAS, 0);
  delay(500);
  detenerMotor();
}
void detenerMotor() {
  digitalWrite(MOTOR_IZQ_ADELANTE, 0);
  digitalWrite(MOTOR_IZQ_ATRAS, 0);
  digitalWrite(MOTOR_DER_ADELANTE, 0);
  digitalWrite(MOTOR_DER_ATRAS, 0);
}




void setup() {
  pinMode (Activa1, OUTPUT);
  pinMode(MOTOR_IZQ_ADELANTE, OUTPUT);
  pinMode(MOTOR_IZQ_ATRAS, OUTPUT);
  pinMode(MOTOR_DER_ADELANTE, OUTPUT);
  pinMode(MOTOR_DER_ATRAS, OUTPUT);
  pinMode (Activa2, OUTPUT);
  analogWrite(Activa1,velocidad);
  analogWrite(Activa2,velocidad);
// Inicializar comunicación serial para depuración
  Serial.begin(9600);
/*
  pinMode (13,OUTPUT);
    servito.attach(3);
*/  
}




long medirDistancia(int triggerPin, int echoPin) {
    digitalWrite(triggerPin, 0);
    delayMicroseconds(2);
    digitalWrite(triggerPin, 1);
    delayMicroseconds(10);
    digitalWrite(triggerPin, 0);
    return pulseIn(echoPin, 1) / 58;  // Convierte el tiempo en distancia en cm
}

  
void loop() {
    avanzarAdelante();
      delay(5000); // Espera 5 segundos para retroceder
    retroceder();
      delay(5000);
     
     for(int i = 0; i < 12; i++) {  // Repetir 12 veces
// Medir distancia del sensor IZQUIERDO (trigpin2, echopin2)
    long distanciaIzquierda = medirDistancia(trigpin2, echopin2);
    
    Serial.print("Iteración ");
    Serial.print(i+1);
    Serial.print(": Distancia izquierda = ");
    Serial.print(distanciaIzquierda);
    Serial.println(" cm");
    
    if(distanciaIzquierda > 100) {
      girarIzquierda();  // Si >100cm, gira izquierda
      Serial.println("Girando a la izquierda");
    } else {
      girarDerecha();    // Si <=100cm, gira derecha
      Serial.println("Girando a la derecha");
    }
 
    delay(500);  // Pausa entre iteraciones
  }
      detenerMotor();
    Serial.println("Ciclo completado");
    while(true);  // Detener ejecución
}
/*
      delay(3000); // Espera 5 segundos antes de repetir el movimiento
      long distanciaIzquierda = medirDistancia(trigpin2,echopin2);
      Serial.print("Distancia izquierda: ");
      Serial.println(distanciaIzquierda);      
      if (distanciaIzquierda < ) {  // Umbral para detectar obstáculos
        girarDerecha();
      } else {
      // Mantener el movimiento recto
        digitalWrite(MOTOR_IZQ_ADELANTE, 1);
        digitalWrite(MOTOR_IZQ_ATRAS, 0);
        digitalWrite(MOTOR_DER_ADELANTE, 1);
        digitalWrite(MOTOR_DER_ATRAS, 0);
        delay(3000); // Pequeña pausa para evitar lecturas demasiado frecuentes


      }
*/
}

/*
//Atras
 digitalWrite(Ma1,0);
 digitalWrite(Ma2,1);
 digitalWrite(Mb1,0);
 digitalWrite(Mb2,1);
 digitalWrite(13,0);
 delay(3000);
//Avanzar
 digitalWrite(Ma1,1);
 digitalWrite(Ma2,0);
 digitalWrite(Mb1,1);
 digitalWrite(Mb2,0);
 digitalWrite(13,1);
  delay(1000);
   servito.write(90);
 delay (1000);
  servito.write(0);
  delay (1000);
*/

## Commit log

2025-06-26 Motorreductor - Datasheet.pdf
2025-06-26 Motorreductor - Datasheet.md
2025-06-26 Create Motorreductor
2025-07-01 Create circuit explanation.md
2025-07-01 Update circuit explanation.md
2025-07-01 Rename circuit diagram.jpg to circuitdiagram.jpg
2025-07-01 Update and rename wro2022-fe-template/src/Servomotor.ino to wro2022-fe-template/src/V1/Servomotor.ino
